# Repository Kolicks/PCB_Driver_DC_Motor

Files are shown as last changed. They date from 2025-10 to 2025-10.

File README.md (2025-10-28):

# ⚡ PCB_DC_Driver
**Single DC Motor Driver with H-Bridge Architecture**

---

<p align="center">
  <a href="https://github.com/Kolicks/PCB_Driver_DC_Motor" target="_blank">
    
  </a>
</p>

---

## 📘 Overview
**PCB_DC_Driver** is a theoretical yet practical design for a **DC motor driver** built around an **H-Bridge architecture** using dedicated gate drivers.  
The project focuses on achieving an efficient, compact, and manufacturable design while following **Design for Assembly (DFA)** and **Design for Manufacturing (DFM)** principles.

<p align="center">
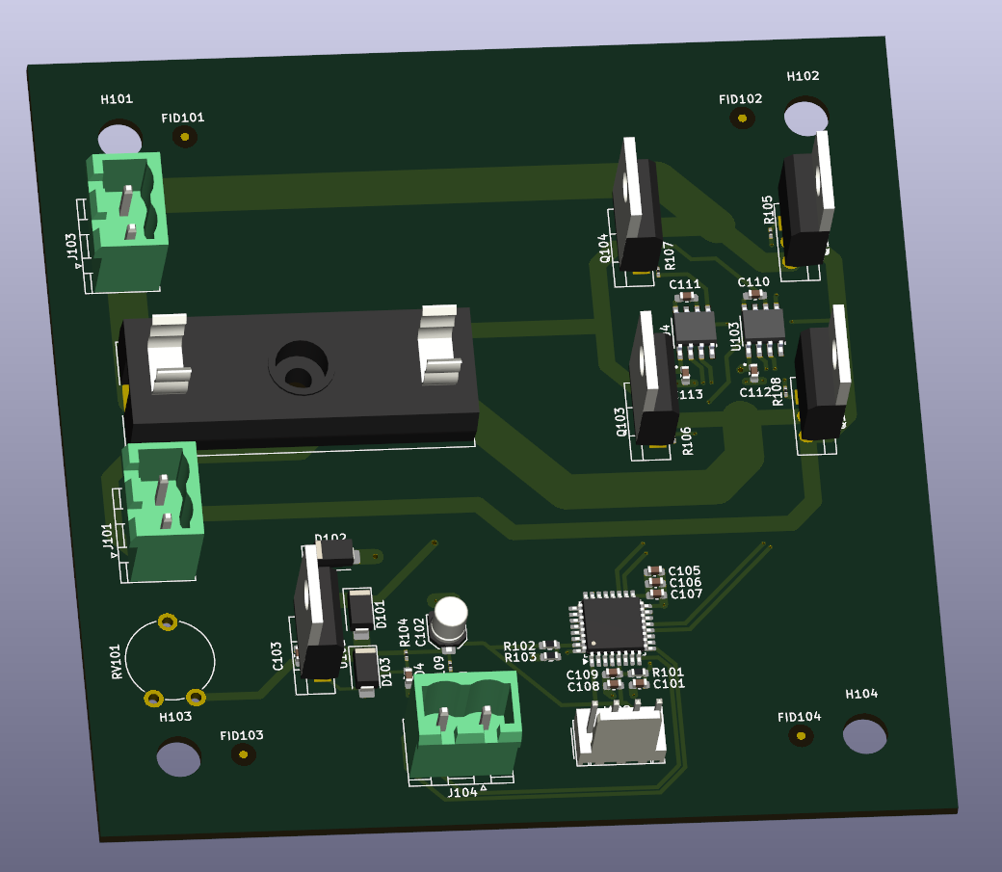
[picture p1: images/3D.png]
3D Render
  
  <br>
  <em>3D render of the finished PCB_DC_Driver board</em>
</p>

---

## ⚙️ General Information
- Theoretical **simple DC driver** implementing an **H-Bridge** with gate drivers.  
- Designed with **DFA** considerations to optimize ease of assembly and production workflow.  
- Built on **2 layers**, using **standard FR4 (TG135)** core and prepreg stackup, **1.6 mm thickness**.  

<p align="center">
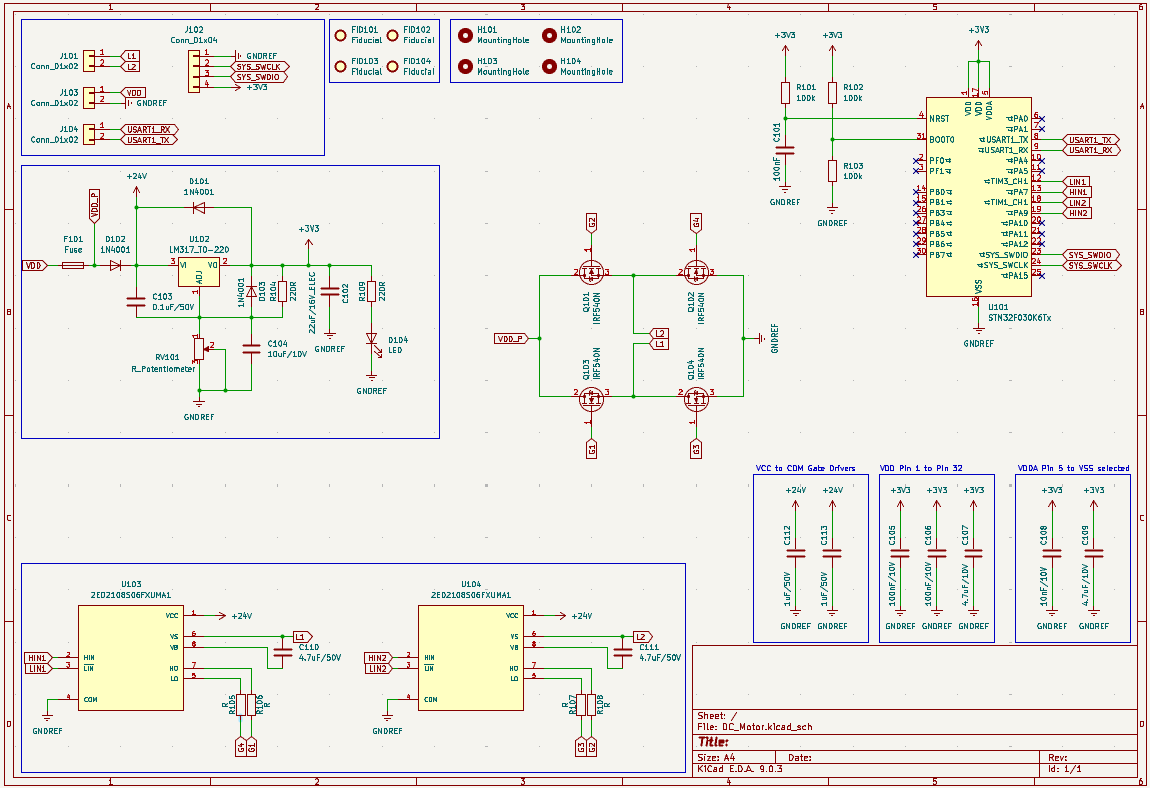
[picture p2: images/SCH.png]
Schematic
  
  <br>
  <em>Full schematic diagram of the PCB_DC_Driver (KiCad 9)</em>
</p>

---

## 🔧 Characteristics
- Controls **one DC motor** with full H-Bridge operation.  
- Supports up to **10 A continuous current**, limited by the gate drivers and onboard fuse.  
- Operates at **24 VDC** nominal input voltage.  
- **All high-current power lanes routed on the top layer** to simplify current flow and reduce noise.  
- **All components placed on the top side**, enabling a **two-step DFA process**:  
  - Reflow soldering for SMD components.  
  - Wave soldering for through-hole parts.  
- **DFM-compliant design**:  
  - Includes multiple **mounting holes**.  
  - **Maximum PCB size:** 100 × 100 mm (optimized for **JLCPCB**).  
  - **Surface finish:** HASL (with lead).  
  - **Tented vias** for protection and manufacturing consistency.  
- **Optimized gate loop design:**  
  - Gate drivers positioned close to MOSFETs to minimize loop inductance.  
  - Bottom ground layer cleared in high-current paths to ensure controlled current direction and reduce EMI/EMC issues.
- **Space between MOSFET**: For a 20x15 Mounted radiators space. 
- **Microcontroller:** Reused **STM32F030K6T6** from previous projects for convenience, reusability, and familiarity with existing firmware.

<p align="center">
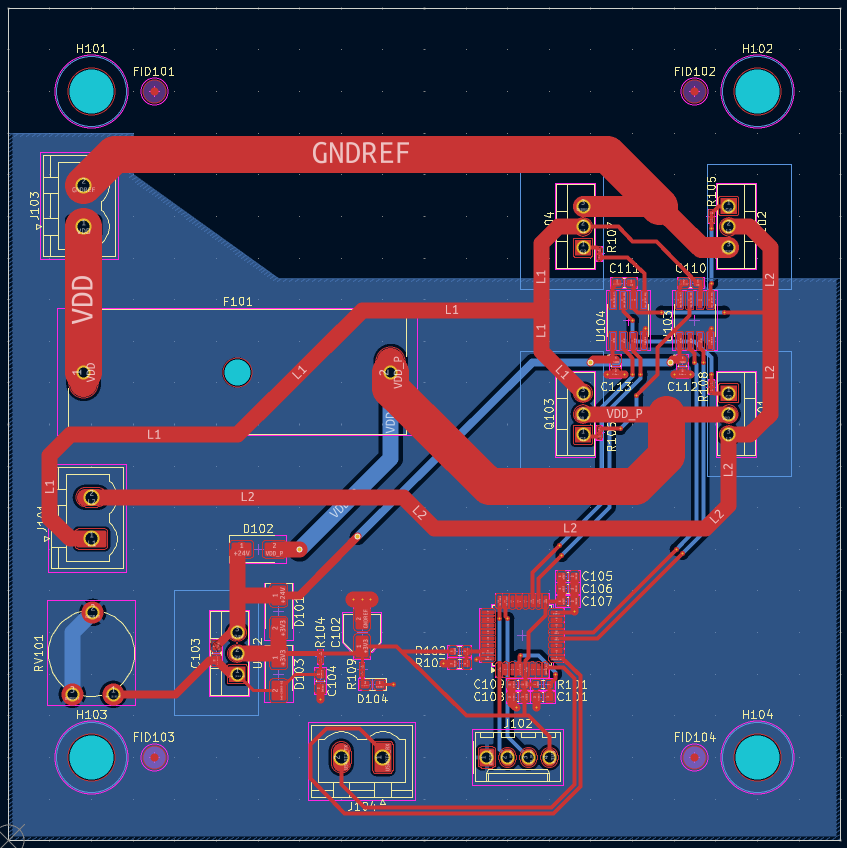
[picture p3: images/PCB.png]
PCB Layout
  
  <br>
  <em>Top layer routing and overall PCB layout (KiCad 9)</em>
</p>

---

## ⚠️ Design Notes
- Power paths designed with proper copper width for 10 A continuous load capability.  
- Ground and power planes isolated to improve switching behavior and minimize noise coupling.  
- Routing and layout optimized for **EMI/EMC performance**.  
- Designed for **expandability**, allowing integration of PWM control, fault sensing, or current feedback in future iterations.  

---

## 🧩 Repository Structure
PCB_DC_Driver/

├── schematic/ # KiCad schematic files

├── pcb_layout/ # KiCad PCB layout files

├── gerbers/ # Gerber fabrication files

├── images/ # Rendered visuals (3D, SCH, PCB)

├── LICENSE # Hardware license (CERN-OHL-P v2.0)

└── README.md # Project documentation

---

## 📜 License
This hardware design is released under the **CERN Open Hardware License v2 – Permissive (CERN-OHL-P-2.0)**.  
You are free to use, modify, and distribute this design, provided that:
- The license is included with redistributions.
- Proper credit is given to the original author.

More info: https://cern-ohl.web.cern.ch/

---

## 👤 Author
**Project:** PCB_DC_Driver  
**Author:** [Kolicks]  
**Toolchain:** KiCad 9  
**Version:** 9.0  

---

## 🧱 Future Improvements

- **Thermal Management:**  
  - Integrate larger or multi-via thermal pads under the MOSFETs and drivers to enhance heat dissipation.  
  - Evaluate adding **heatsinks or via arrays** for improved performance under sustained 10 A load.  

- **Power Optimization:**  
  - Consider using **2 oz copper** for better current capacity and lower resistive losses.  
  - Evaluate a **four-layer design** with dedicated GND and VCC planes for improved EMI and power distribution.  

- **Protection & Monitoring:**  
  - Add **current sense resistors** and amplifiers for real-time feedback and overcurrent protection.  
  - Implement **reverse polarity**, **undervoltage**, and **thermal shutdown** protection.  
  - Include **snubber or flyback diode networks** to suppress switching transients.  

- **Diagnostics & User Interface:**  
  - Integrate **LED indicators** for power, fault, and enable states.  
  - Add **test points** for gate and driver outputs for easier debugging and measurement.  

- **Control Enhancements:**  
  - Implement **PWM-based speed and direction control** in firmware.  
  - Add **UART or CAN communication** for remote control and telemetry.  
  - Enable **firmware upgradability** via USB or serial interface.  

- **Mechanical & Assembly Improvements:**  
  - Add **mounting supports for heatsinks or enclosures**.  
  - Improve **silkscreen labeling** for connectors and test points.  
  - Optimize **component placement** for serviceability and rework.  

---

⭐ *If you find this project useful or educational, please consider starring the repository and sharing feedback!*

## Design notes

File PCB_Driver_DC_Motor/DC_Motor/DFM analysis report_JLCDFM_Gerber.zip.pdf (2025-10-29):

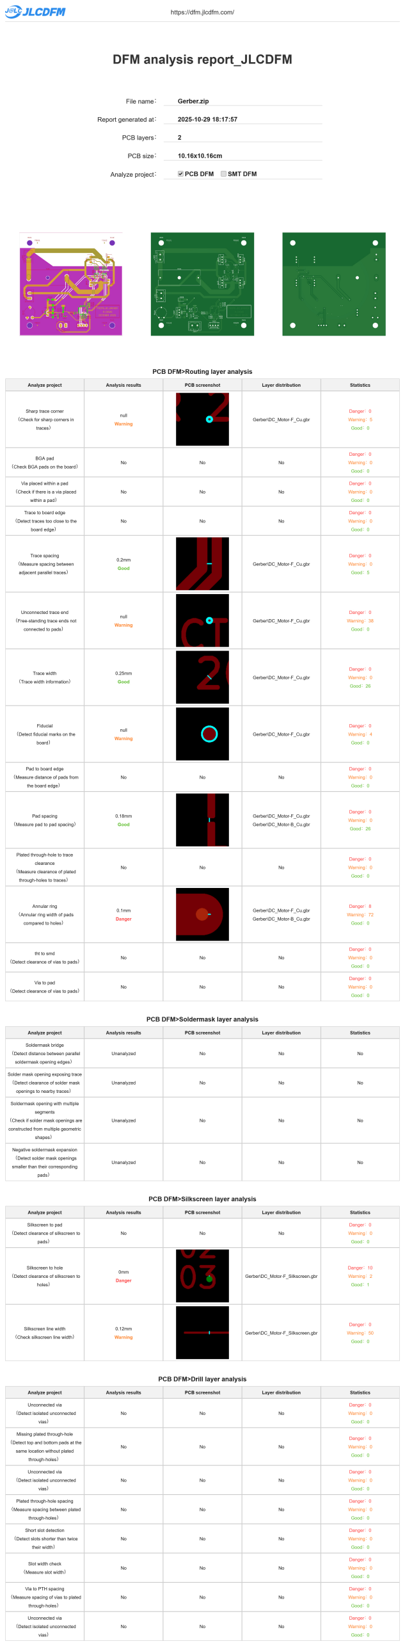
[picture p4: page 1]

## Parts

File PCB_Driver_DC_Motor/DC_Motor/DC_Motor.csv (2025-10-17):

Reference | Qty | Value | DNP | Exclude from BOM | Exclude from Board | Footprint | Datasheet
C101 | 1 | 100nF |  |  |  | Capacitor_SMD:C_0603_1608Metric | ~
C102 | 1 | 22uF/16V_ELEC |  |  |  | Capacitor_SMD:C_Elec_4x5.4 | ~
C103 | 1 | 0.1uF/50V |  |  |  | Capacitor_SMD:C_0603_1608Metric_Pad1.08x0.95mm_HandSolder | ~
C104 | 1 | 10uF/10V |  |  |  | Capacitor_SMD:C_0603_1608Metric_Pad1.08x0.95mm_HandSolder | ~
C105,C106 | 2 | 100nF/10V |  |  |  | Capacitor_SMD:C_0603_1608Metric | ~
C107,C109 | 2 | 4.7uF/10V |  |  |  | Capacitor_SMD:C_0603_1608Metric | ~
C108 | 1 | 10nF/10V |  |  |  | Capacitor_SMD:C_0603_1608Metric | ~
C110,C111 | 2 | 4.7uF/50V |  |  |  | Capacitor_SMD:C_0603_1608Metric_Pad1.08x0.95mm_HandSolder | ~
C112,C113 | 2 | 1uF/50V |  |  |  | Capacitor_SMD:C_0603_1608Metric | ~
D101,D102,D103 | 3 | 1N4001 |  |  |  | Diode_SMD:D_SMA | http://www.vishay.com/docs/88503/1n4001.pdf
D104 | 1 | LED |  |  |  | LED_SMD:LED_0603_1608Metric_Pad1.05x0.95mm_HandSolder | ~
F101 | 1 | Fuse |  |  |  | Fuse:Fuseholder_Cylinder-6.3x32mm_Schurter_0031-8002_Horizontal_Open | ~
FID101,FID102,FID103,FID104 | 4 | Fiducial |  | Excluded from BOM |  | Fiducial:Fiducial_1mm_Mask3mm | ~
H101,H102,H103,H104 | 4 | MountingHole |  | Excluded from BOM |  | MountingHole:MountingHole_5.3mm_M5_ISO14580 | ~
J101,J103,J104 | 3 | Conn_01x02 |  |  |  | Connector_Phoenix_MSTB:PhoenixContact_MSTBVA_2,5_2-G-5,08_1x02_P5.08mm_Vertical | ~
J102 | 1 | Conn_01x04 |  |  |  | Connector_Molex:Molex_KK-254_AE-6410-04A_1x04_P2.54mm_Vertical | ~
Q101,Q102,Q103,Q104 | 4 | IRF540N |  |  |  | Package_TO_SOT_THT:TO-220-3_Vertical | http://www.irf.com/product-info/datasheets/data/irf540n.pdf
R101,R102,R103 | 3 | 100k |  |  |  | Resistor_SMD:R_0603_1608Metric | ~
R104,R109 | 2 | 220R |  |  |  | Resistor_SMD:R_0201_0603Metric_Pad0.64x0.40mm_HandSolder | ~
R105,R106,R107,R108 | 4 | R |  |  |  | Resistor_SMD:R_0201_0603Metric_Pad0.64x0.40mm_HandSolder | ~
RV101 | 1 | R_Potentiometer |  |  |  | Potentiometer_THT:Potentiometer_Piher_PT-10-V10_Vertical | ~
U101 | 1 | STM32F030K6Tx |  |  |  | Package_QFP:LQFP-32_7x7mm_P0.8mm | https://www.st.com/resource/en/datasheet/stm32f030k6.pdf
U102 | 1 | LM317_TO-220 |  |  |  | Package_TO_SOT_THT:TO-220-3_Vertical | http://www.ti.com/lit/ds/symlink/lm317.pdf
U103,U104 | 2 | 2ED2108S06FXUMA1 |  |  |  | Gate_Driver:SOIC127P600X172-8N

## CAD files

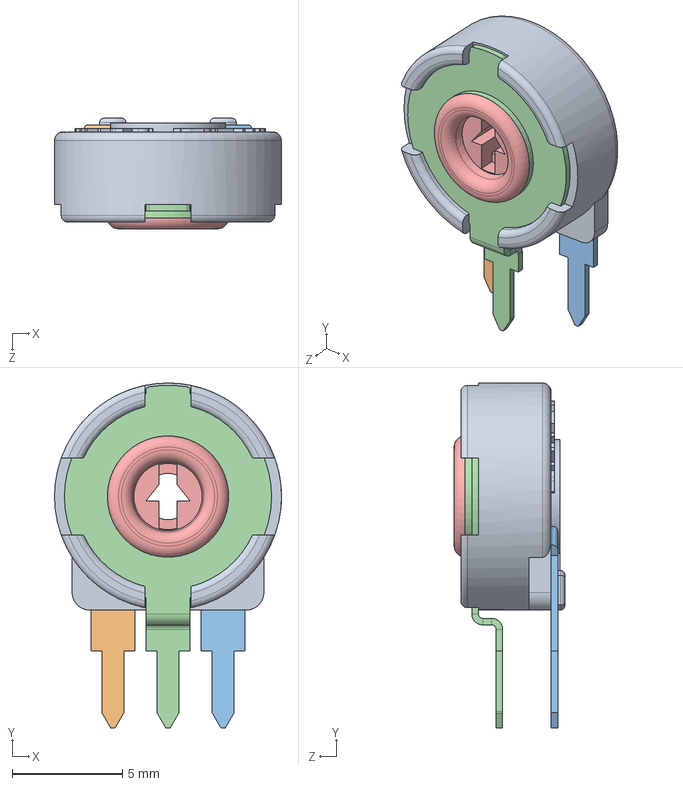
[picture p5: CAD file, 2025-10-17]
PCB_Driver_DC_Motor/DC_Motor/Project_Library/12-PIHER_3D_PT10/PT10_PTC10/PT10_PTC10_10LH01.STEP
10.3 x 15.7 x 5.02 mm
PT10LH01-CARCASA
PT10LH01-TERMINAL DERECHO
PT10LH01-TERMINAL IZQUIERDO
PT10LH01-COLECTOR
PT10LH01-PORTACURSOR_Predeterminada

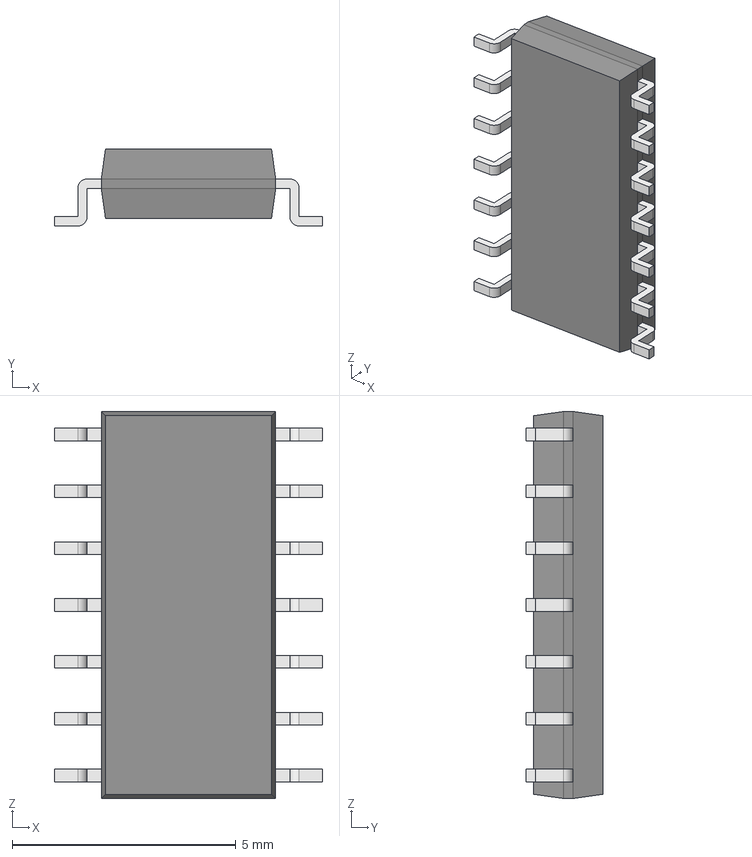
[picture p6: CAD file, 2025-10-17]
PCB_Driver_DC_Motor/DC_Motor/Project_Library/2ED21084S06JXUMA1/2ED21084S06JXUMA1.step
6.00 x 1.72 x 8.65 mm
Body001 (Mirror #1) x 7
XY-plane x 12
X-axis x 12

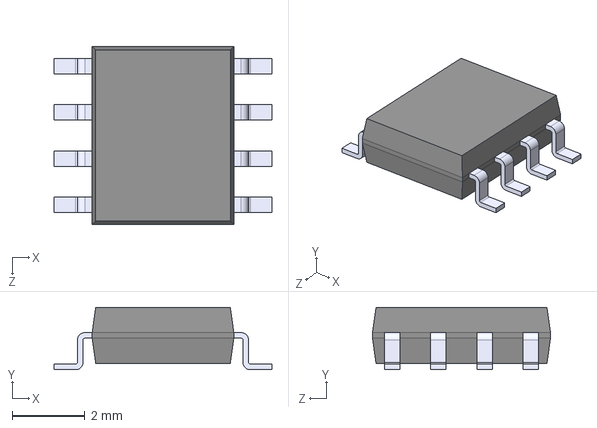
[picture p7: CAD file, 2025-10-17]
PCB_Driver_DC_Motor/DC_Motor/Project_Library/2ED2108S06FXUMA1/2ED2108S06FXUMA1.step
6.00 x 1.72 x 4.90 mm

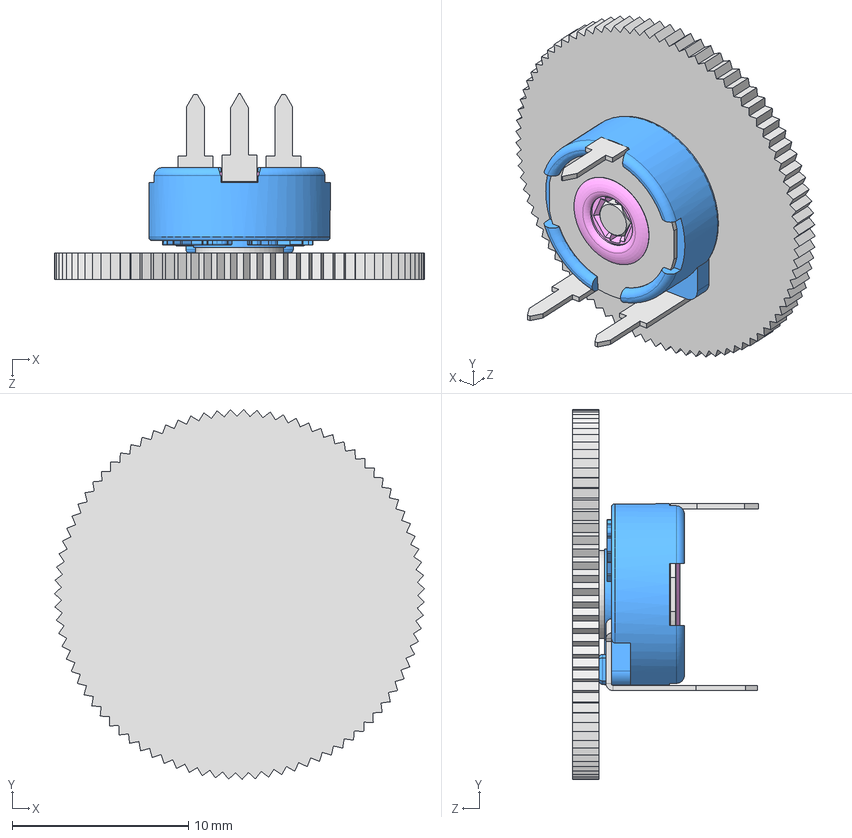
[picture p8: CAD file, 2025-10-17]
PCB_Driver_DC_Motor/DC_Motor/Project_Library/12-PIHER_3D_PT10/PT10_PTC10/PT10WV10 Knob fig. 17.STEP
21.0 x 21.0 x 10.5 mm
58A01-2-PT10MV10

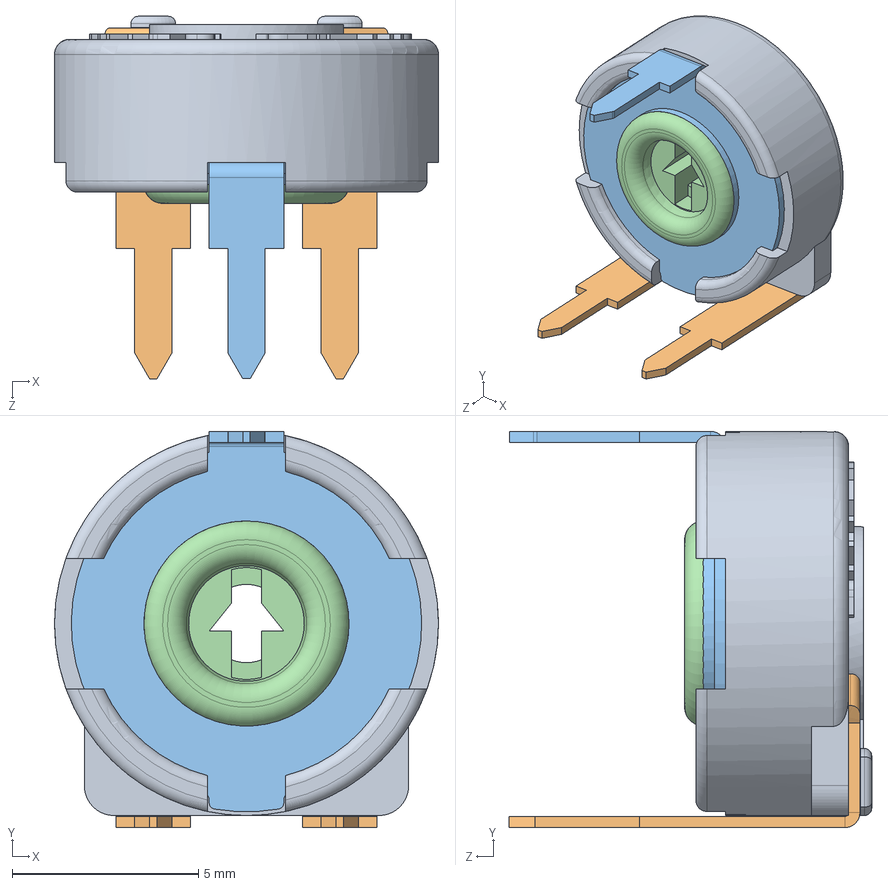
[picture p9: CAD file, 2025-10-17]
PCB_Driver_DC_Motor/DC_Motor/Project_Library/12-PIHER_3D_PT10/PT10_PTC10/PT10_PTC10_LV10.STEP
10.3 x 10.6 x 9.72 mm
PT10LV10-CARCASA
PT10LV10-TERMINAL DERECHO
PT10LV10-TERMINAL IZQUIERDO
PT10LV10-COLECTOR REBORDEADO
PT10LV10-PORTACURSOR_Predeterminada

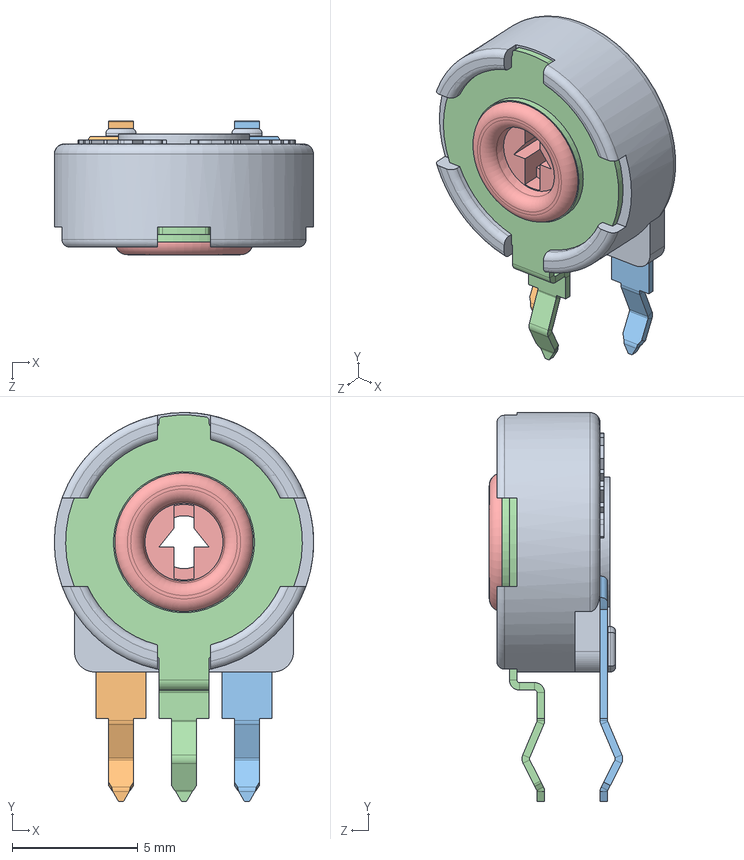
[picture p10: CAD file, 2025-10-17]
PCB_Driver_DC_Motor/DC_Motor/Project_Library/12-PIHER_3D_PT10/PT10_PTC10/PT10_PTC10_LH02.STEP
10.3 x 15.4 x 5.30 mm
PT10LH02-CARCASA
PT10LH02-TERMINAL DERECHO
PT10LH02-TERMINAL IZQUIERDO
PT10LH02-COLECTOR
PT10LH02-PORTACURSOR_Predeterminada

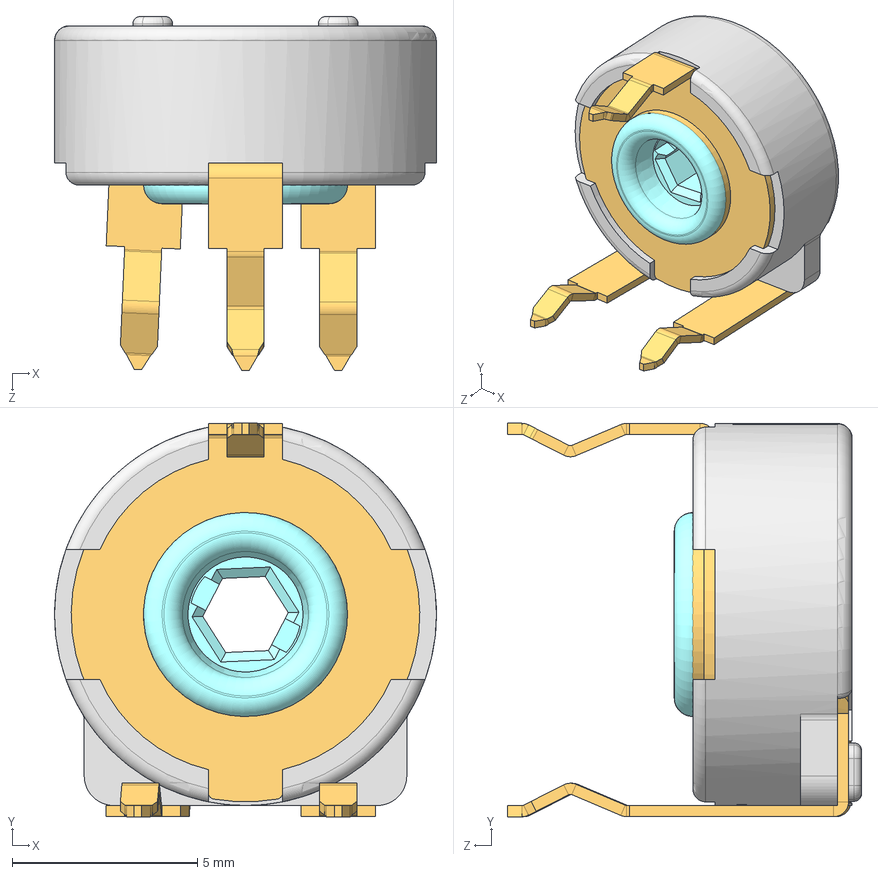
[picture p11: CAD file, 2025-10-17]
PCB_Driver_DC_Motor/DC_Motor/Project_Library/12-PIHER_3D_PT10/PT10_PTC10/PT10MV13.STEP
10.3 x 10.6 x 9.55 mm

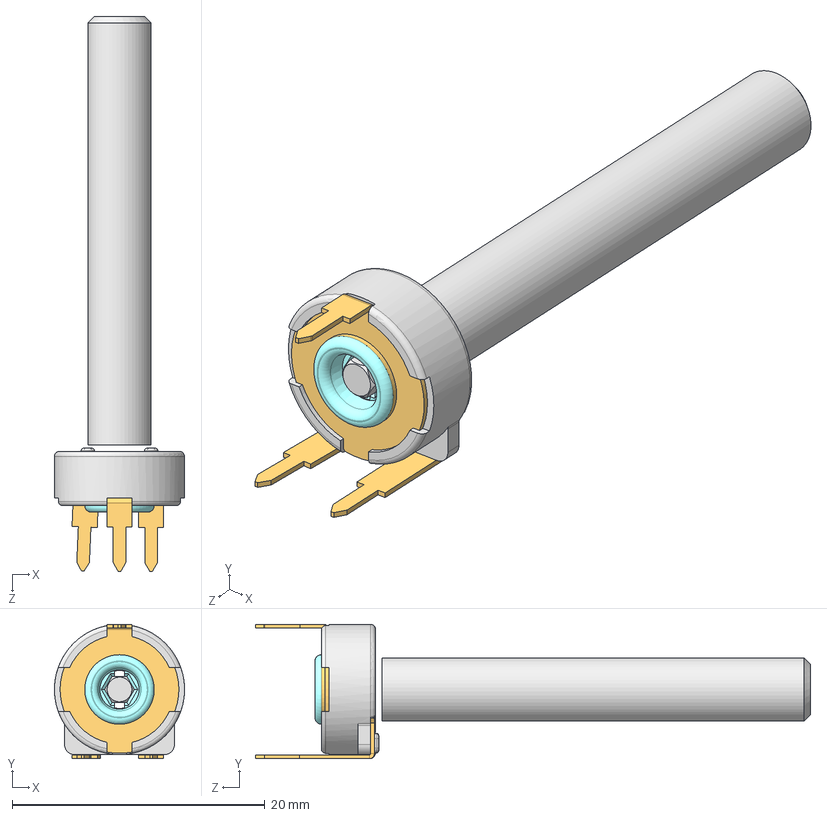
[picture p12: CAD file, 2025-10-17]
PCB_Driver_DC_Motor/DC_Motor/Project_Library/12-PIHER_3D_PT10/PT10_PTC10/PT10_PTC10_WV10 fig. 4.STEP
10.3 x 10.6 x 43.9 mm

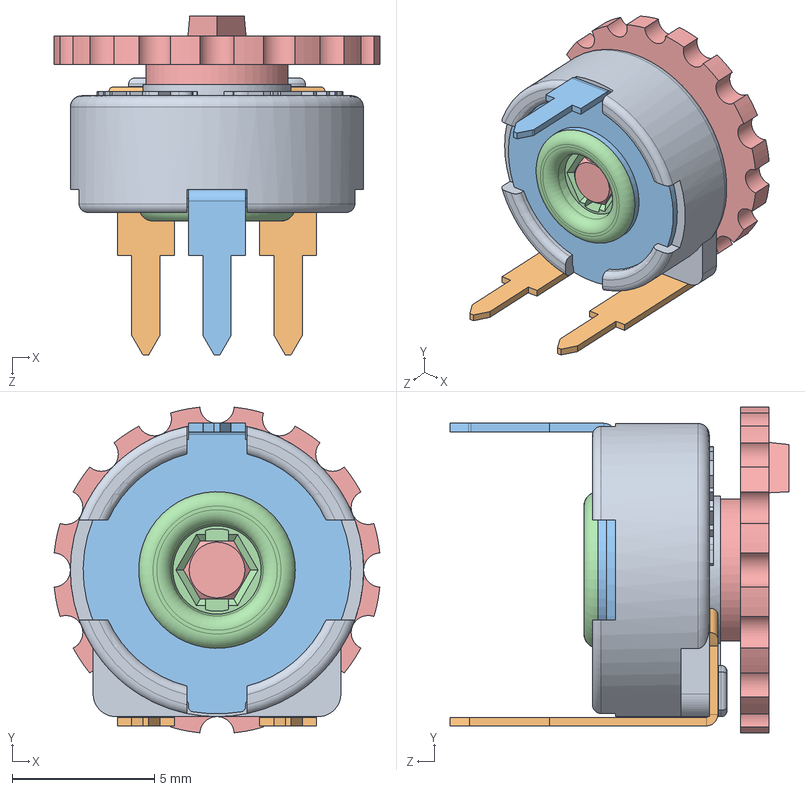
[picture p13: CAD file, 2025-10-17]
PCB_Driver_DC_Motor/DC_Motor/Project_Library/12-PIHER_3D_PT10/PT10_PTC10/PT10_PTC10_YV10-FIG 05.STEP
11.4 x 11.4 x 11.9 mm
PT10YV10-FIG 05-CARCASA
PT10YV10-FIG 05-TERMINAL DERECHO
PT10YV10-FIG 05-TERMINAL IZQUIERDO
PT10YV10-FIG 05-COLECTOR
PT10YV10-FIG 05-PORTACURSOR_Predeterminada
PT10YV10-FIG 05-BOTON

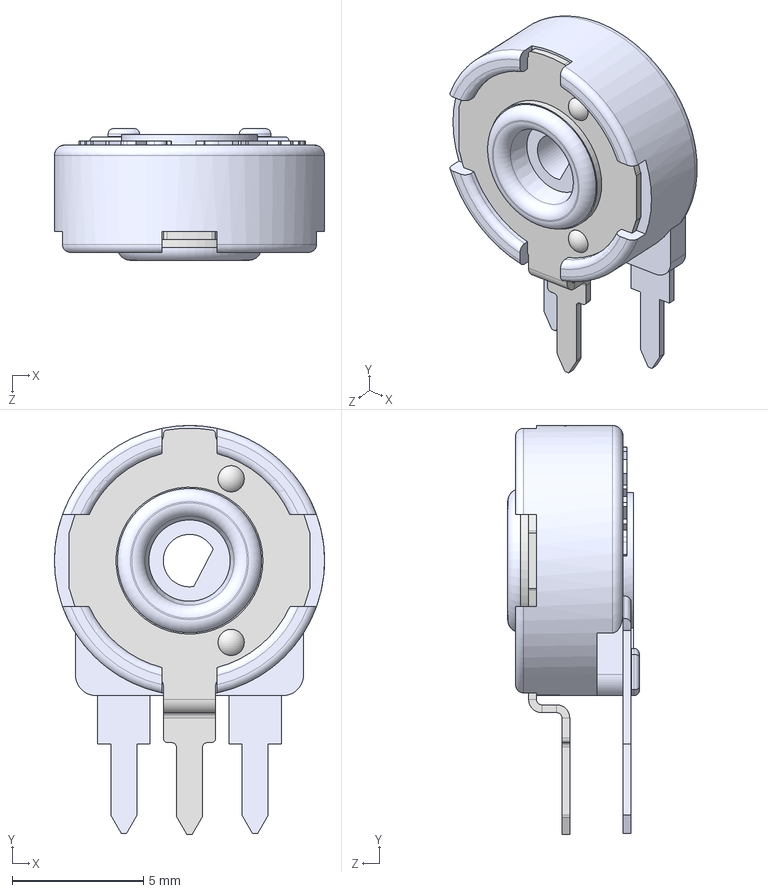
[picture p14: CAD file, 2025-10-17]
PCB_Driver_DC_Motor/DC_Motor/Project_Library/12-PIHER_3D_PT10/PT10_PTC10/PT10RH01 P02.STEP
10.3 x 15.6 x 5.02 mm

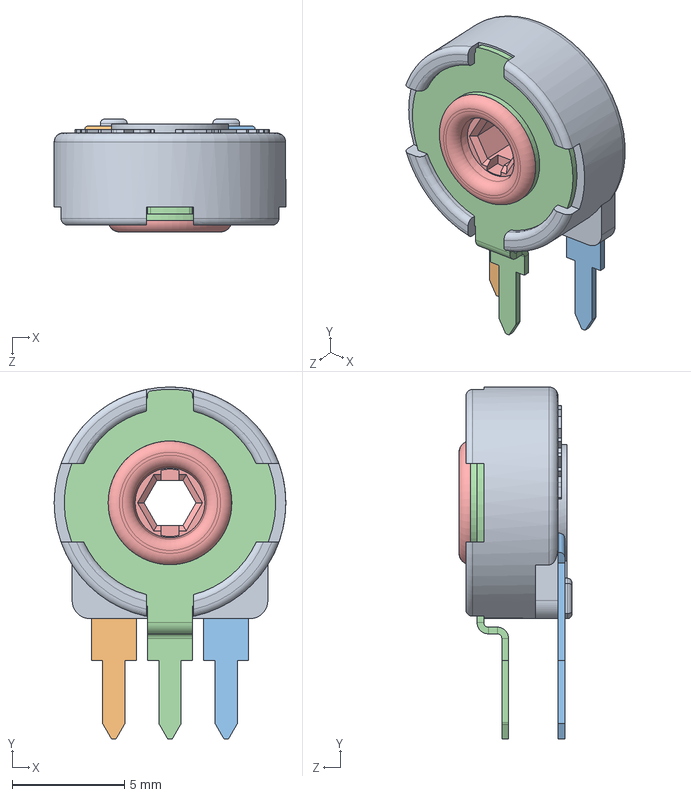
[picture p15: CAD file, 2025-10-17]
PCB_Driver_DC_Motor/DC_Motor/Project_Library/12-PIHER_3D_PT10/PT10_PTC10/PT10_PTC10_MH01.STEP
10.3 x 15.7 x 5.02 mm
PT10MH01-CARCASA
PT10MH01-TERMINAL DERECHO
PT10MH01-TERMINAL IZQUIERDO
PT10MH01-COLECTOR
PT10MH01-PORTACURSOR_Predeterminada

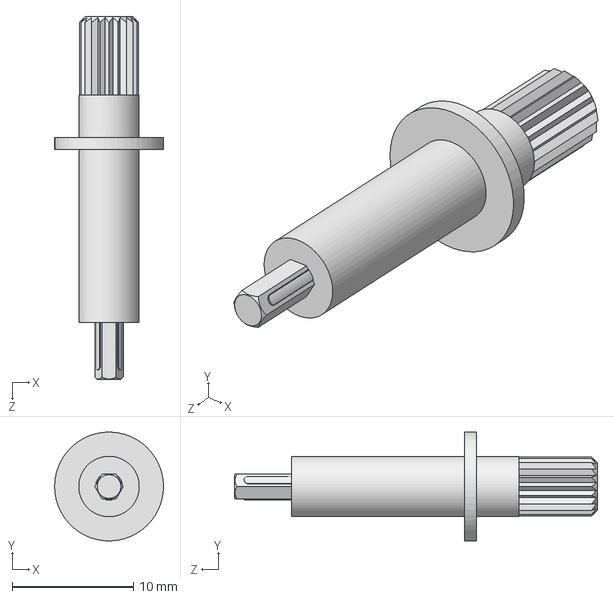
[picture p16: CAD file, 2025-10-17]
PCB_Driver_DC_Motor/DC_Motor/Project_Library/12-PIHER_3D_PT10/PT10_PTC10/Shaft 5115.STEP
8.99 x 9.00 x 30.0 mm

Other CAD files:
PCB_Driver_DC_Motor/DC_Motor/Project_Library/12-PIHER_3D_PT10/PT10_PTC10/PT10_PTC10_MV10.STEP
PCB_Driver_DC_Motor/DC_Motor/Project_Library/12-PIHER_3D_PT10/PT10_PTC10/PT10_PTC10_BV10.STEP
PCB_Driver_DC_Motor/DC_Motor/Project_Library/12-PIHER_3D_PT10/PT10_PTC10/PT10_PTC10_V10.STEP
PCB_Driver_DC_Motor/DC_Motor/Project_Library/12-PIHER_3D_PT10/PT10_PTC10/PT10_PTC10_RV10.STEP
PCB_Driver_DC_Motor/DC_Motor/Project_Library/12-PIHER_3D_PT10/PT10_PTC10/PT10RH01.STEP

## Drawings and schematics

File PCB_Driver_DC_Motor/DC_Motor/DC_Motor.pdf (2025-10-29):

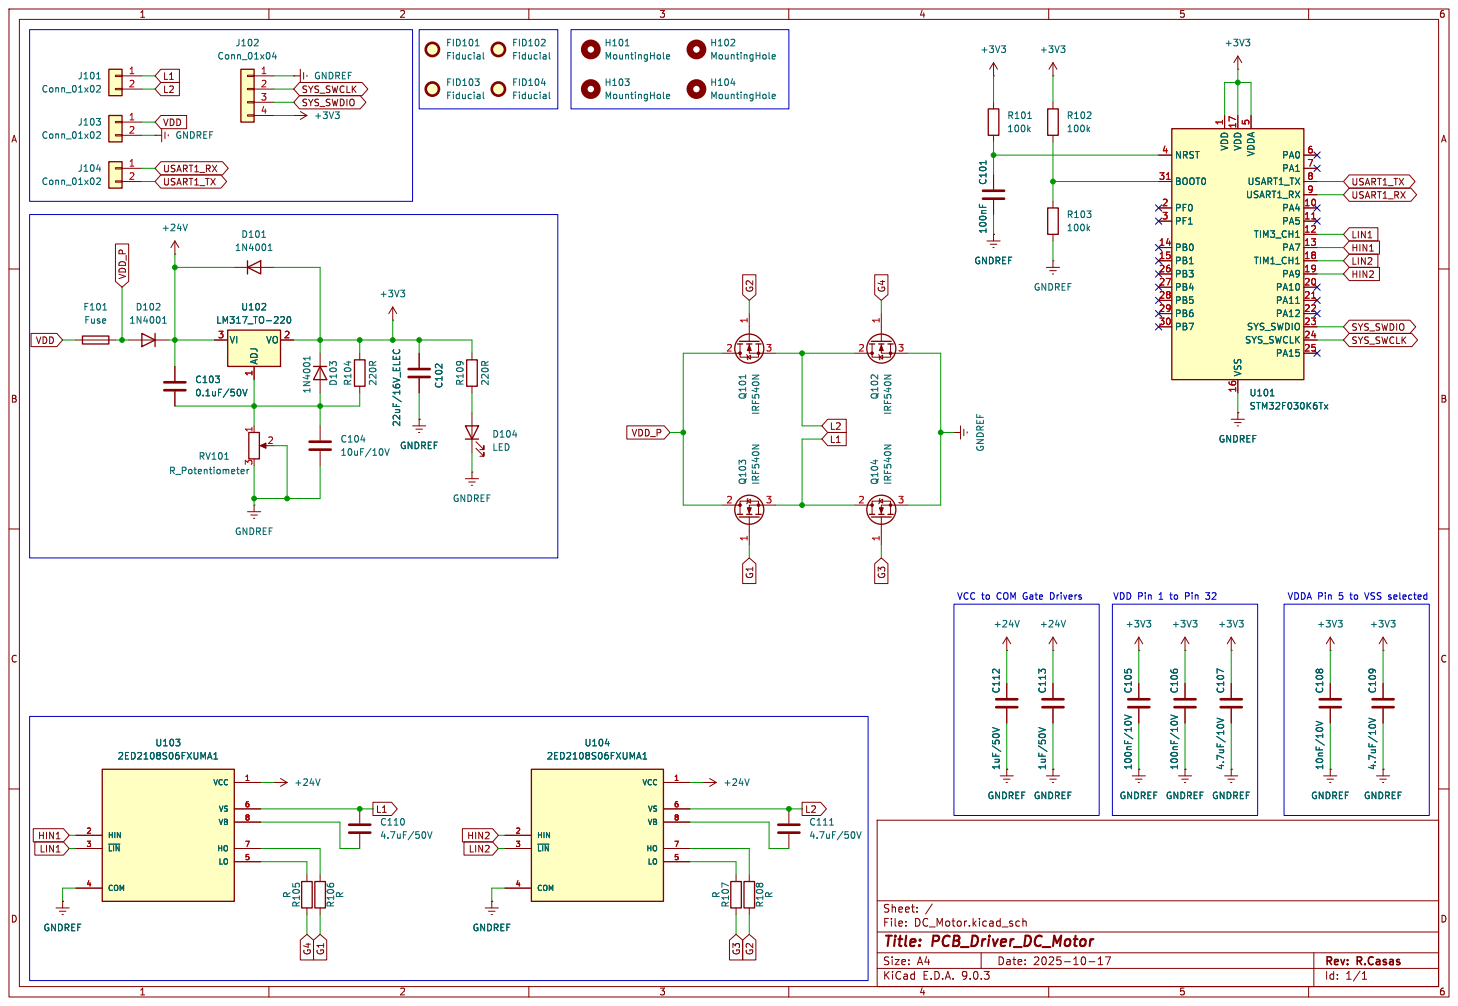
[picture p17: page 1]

Id: 1/1 Title: PCB_Driver_DC_Motor File: DC_Motor.kicad_sch Sheet: /

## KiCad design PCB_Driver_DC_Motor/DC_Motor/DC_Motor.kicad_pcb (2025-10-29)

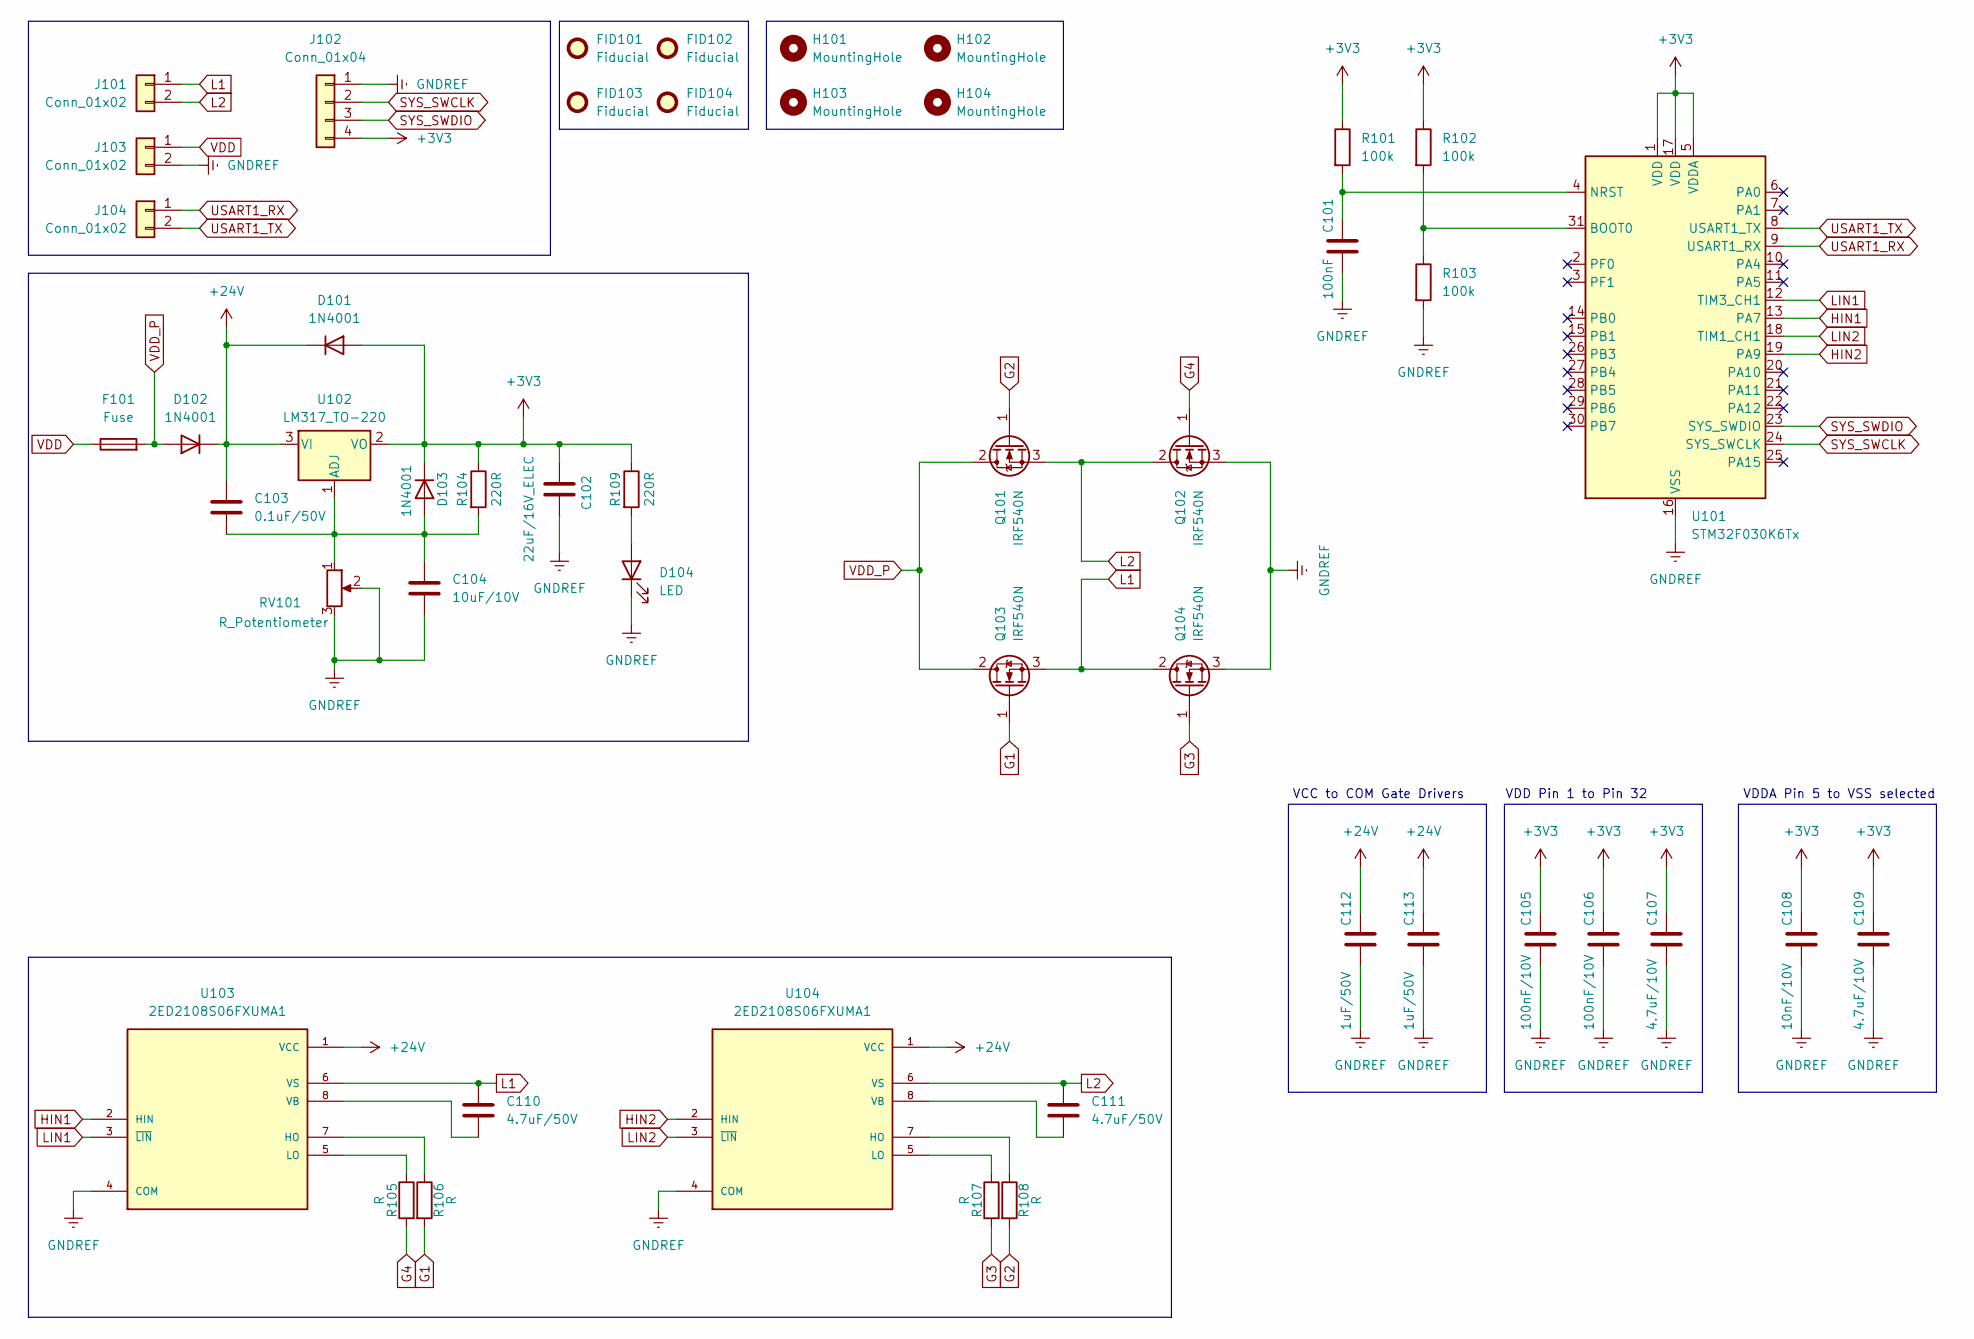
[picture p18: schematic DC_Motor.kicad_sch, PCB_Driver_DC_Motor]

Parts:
C101: 100nF; C_0603_1608Metric
C102: 22uF/16V_ELEC; C_Elec_4x5.4
C103: 0.1uF/50V; C_0603_1608Metric_Pad1.08x0.95mm_HandSolder
C104: 10uF/10V; C_0603_1608Metric_Pad1.08x0.95mm_HandSolder
C105, C106: 100nF/10V; C_0603_1608Metric
C107, C109: 4.7uF/10V; C_0603_1608Metric
C108: 10nF/10V; C_0603_1608Metric
C110, C111: 4.7uF/50V; C_0603_1608Metric_Pad1.08x0.95mm_HandSolder
C112, C113: 1uF/50V; C_0603_1608Metric
D101, D102, D103: 1N4001; D_SMA
D104: LED; LED_0603_1608Metric_Pad1.05x0.95mm_HandSolder
F101: Fuse; Fuseholder_Cylinder-6.3x32mm_Schurter_0031-8002_Horizontal_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
FID101, FID102, FID103, FID104: Fiducial; Fiducial_1mm_Mask3mm
H101, H102, H103, H104: MountingHole; MountingHole_5.3mm_M5_ISO14580
J101, J103, J104: Conn_01x02; PhoenixContact_MSTBVA_2,5_2-G-5,08_1x02_P5.08mm_Vertical
J102: Conn_01x04; Molex_KK-254_AE-6410-04A_1x04_P2.54mm_Vertical
Q101, Q102, Q103, Q104: IRF540N; TO-220-3_Vertical
R101, R102, R103: 100k; R_0603_1608Metric
R104, R109: 220R; R_0201_0603Metric_Pad0.64x0.40mm_HandSolder
R105, R106, R107, R108: R; R_0201_0603Metric_Pad0.64x0.40mm_HandSolder
RV101: R_Potentiometer; Potentiometer_Piher_PT-10-V10_Vertical
U101: STM32F030K6Tx; LQFP-32_7x7mm_P0.8mm
U102: LM317_TO-220; TO-220-3_Vertical
U103, U104: 2ED2108S06FXUMA1; SOIC127P600X172-8N; PARTREV 2.20

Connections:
+3V3: C102.1, C105.1, C106.1, C107.1, C108.1, C109.1, D101.2 (A), D103.1 (K), J102.4, R101.1, R102.1, R104.1, R109.1, U101.1 (VDD), U101.5 (VDDA), U101.17 (VDD), U102.2 (VO)
+24V: C103.1, C112.1, C113.1, D101.1 (K), D102.1 (K), U102.3 (VI), U103.1 (VCC), U104.1 (VCC)
G1: Q103.1 (G), R106.2
G2: Q101.1 (G), R108.2
G3: Q104.1 (G), R107.2
G4: Q102.1 (G), R105.2
GNDREF: C101.2, C102.2, C104.2, C105.2, C106.2, C107.2, C108.2, C109.2, C112.2, C113.2, D104.1 (K), J102.1, J103.2, Q102.3 (S), Q104.3 (S), R103.2, RV101.2, RV101.3, U101.16 (VSS), U101.32 (VSS), U103.4 (COM), U104.4 (COM)
HIN1: U101.13 (PA7), U103.2 (HIN)
HIN2: U101.19 (PA9), U104.2 (HIN)
L1: C110.1, J101.1, Q103.3 (S), Q104.2 (D), U103.6 (VS)
L2: C111.1, J101.2, Q101.3 (S), Q102.2 (D), U104.6 (VS)
LIN1: U101.12 (TIM3_CH1), U103.3 (~LIN)
LIN2: U101.18 (TIM1_CH1), U104.3 (~LIN)
unnamed: C103.2, C104.1, D103.2 (A), R104.2, RV101.1, U102.1 (ADJ)
unnamed: D104.2 (A), R109.2
unnamed: R102.2, R103.1, U101.31 (BOOT0)
unnamed: C101.1, R101.2, U101.4 (NRST)
unnamed: R106.1, U103.7 (HO)
unnamed: R105.1, U103.5 (LO)
unnamed: C110.2, U103.8 (VB)
unnamed: R108.1, U104.7 (HO)
unnamed: R107.1, U104.5 (LO)
unnamed: C111.2, U104.8 (VB)
SYS_SWCLK: J102.2, U101.24 (SYS_SWCLK)
SYS_SWDIO: J102.3, U101.23 (SYS_SWDIO)
USART1_RX: J104.1, U101.9 (USART1_RX)
USART1_TX: J104.2, U101.8 (USART1_TX)
VDD: F101.1, J103.1
VDD_P: D102.2 (A), F101.2, Q101.2 (D), Q103.2 (D)

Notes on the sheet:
VDD Pin 1 to Pin 32
VCC to COM Gate Drivers
VDDA Pin 5 to VSS selected

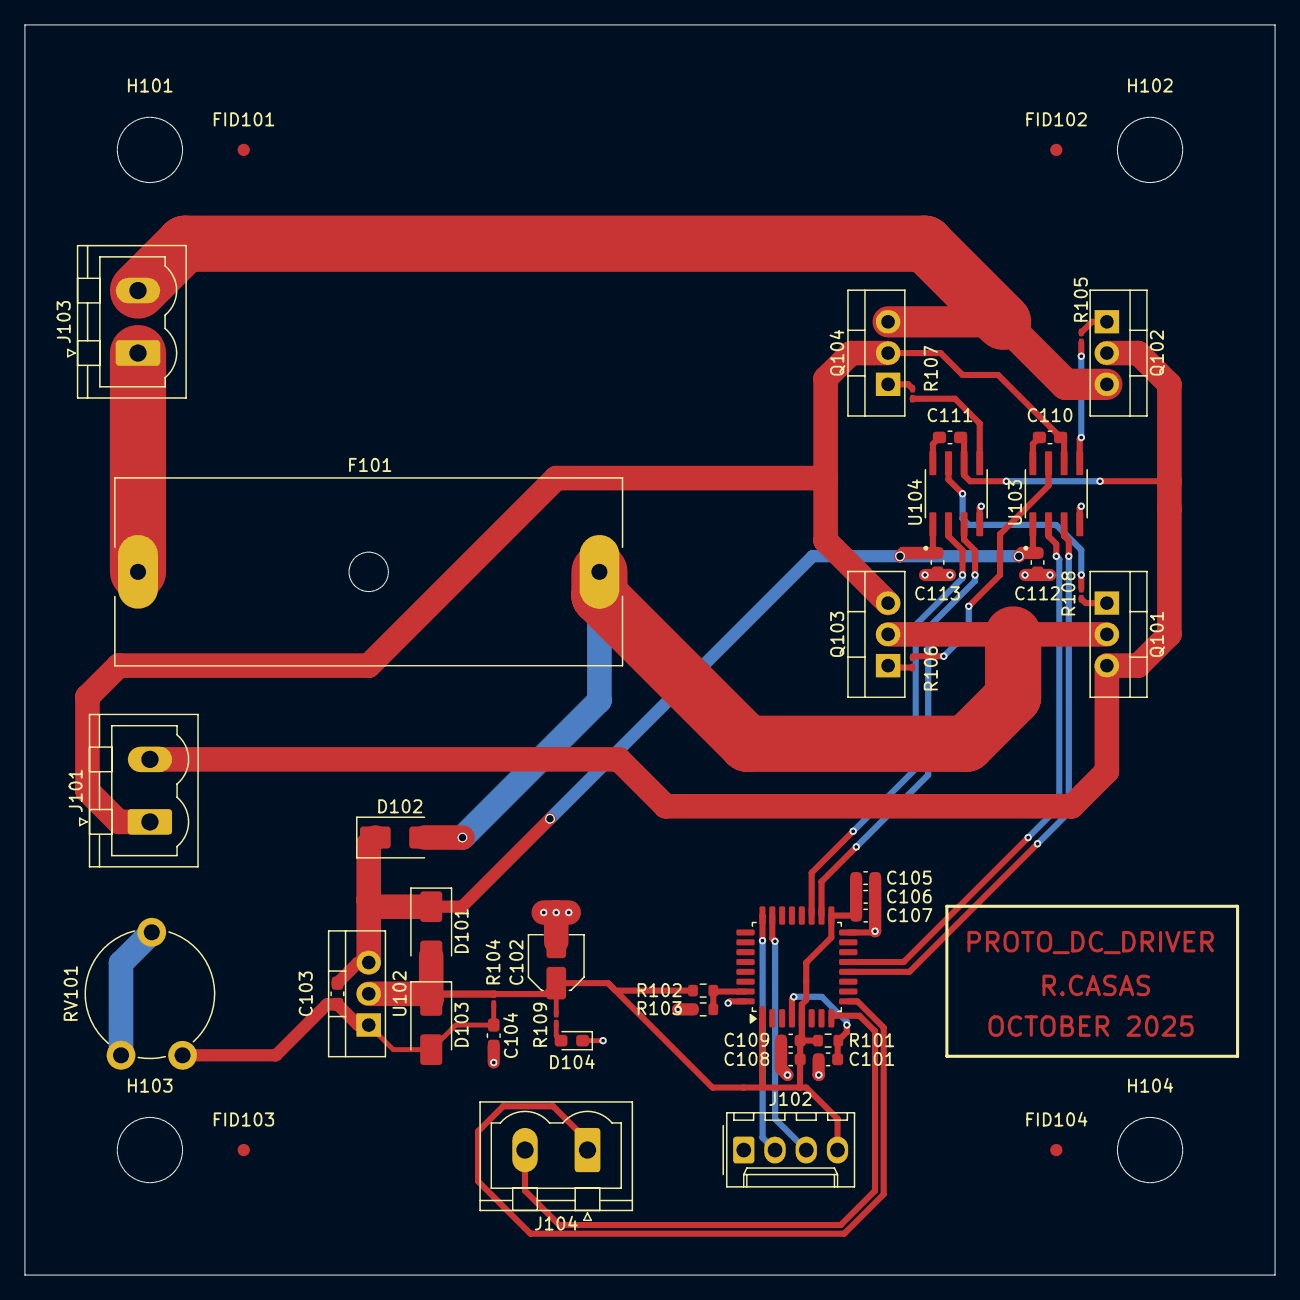
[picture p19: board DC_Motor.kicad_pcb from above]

Board: 2 copper layers, 101.6 x 101.6 mm, 48 parts (0 on the bottom side), 29 nets.

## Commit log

2025-10-17 Update README with MOSFET spacing information
    Added a note about the space between MOSFETs for mounted radiators.
2025-10-17 Update PCB image source in README
